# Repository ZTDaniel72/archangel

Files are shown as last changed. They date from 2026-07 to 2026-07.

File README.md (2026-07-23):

# Archangel

Archangel is an RC aircraft, that is designed to be efficient, and innovative.
It includes a 3D-printed airframe, a CUSTOM MADE ESP32 flight controller, and many more electric parts, discussed below.
The roadmap includes an FPV camera and more sensors with larger range, so that one day, this could stay in the air for 24 hours. But we are quite far from that right now lol.
I am building this because I love aviation and aeronautical engineering and I aspire to be one someday.
My goal is to get into TU Delft, in the Netherlands.

## Features

My current plan is:
Milestone 1: manual RC flight, custom firmware pass-through, failsafe, dual rates
Milestone 2: auto-level stabilization (MPU6500 + PID), SD flight logging
Milestone 3: altitude hold (BMP280), FPV camera
Wel shall see how far in we get, I think we can achieve all, but if not, milestone 2 will for sure be completed.

## Design

- Wingspan: ~110 cm, chord 17 cm (airfoil is a variation of this: http://airfoiltools.com/airfoil/details?airfoil=naca2412-il)
- Wing printed in 5 modules on a Bambu Lab P1S (25.6 cm bed), joined on a 10 mm carbon spar
- Ailerons: Incorporated into the wing structure
- Motor: Surpass Hobby C2836 1120KV, 3S, 9x6 prop
- CAD source: `cad/` (committed work-in-progress each session)

## Pictures
Current state as of 07.24:

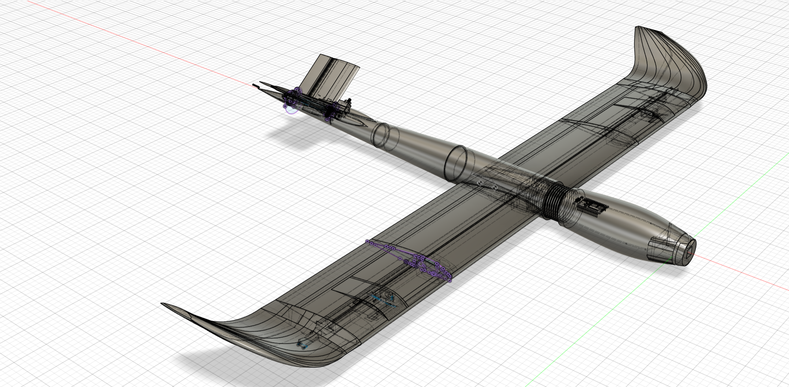
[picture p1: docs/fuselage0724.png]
Fuselage


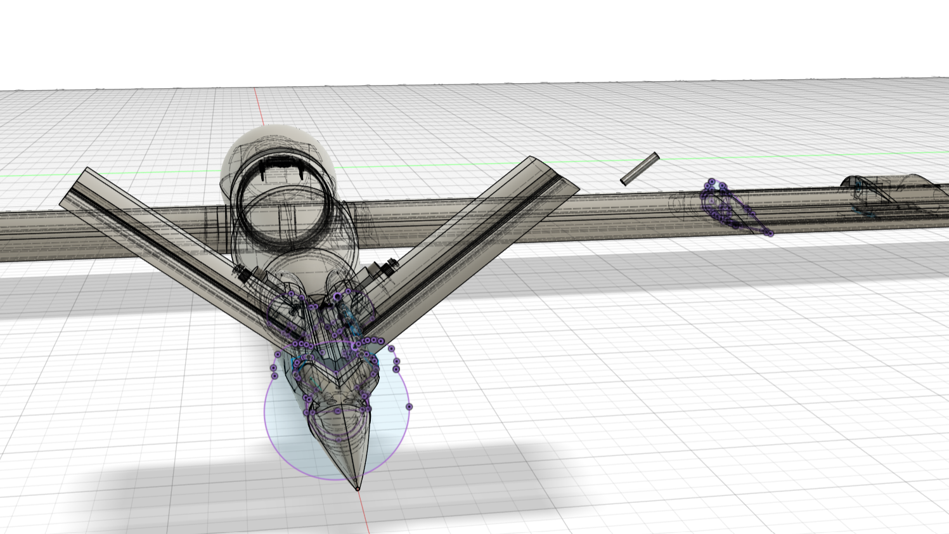
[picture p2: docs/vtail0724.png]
V-tail mount


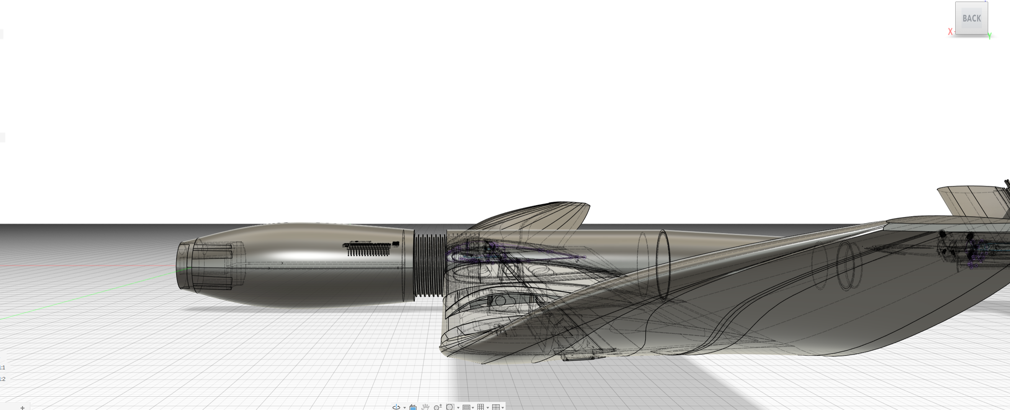
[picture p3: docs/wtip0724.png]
Wing preview


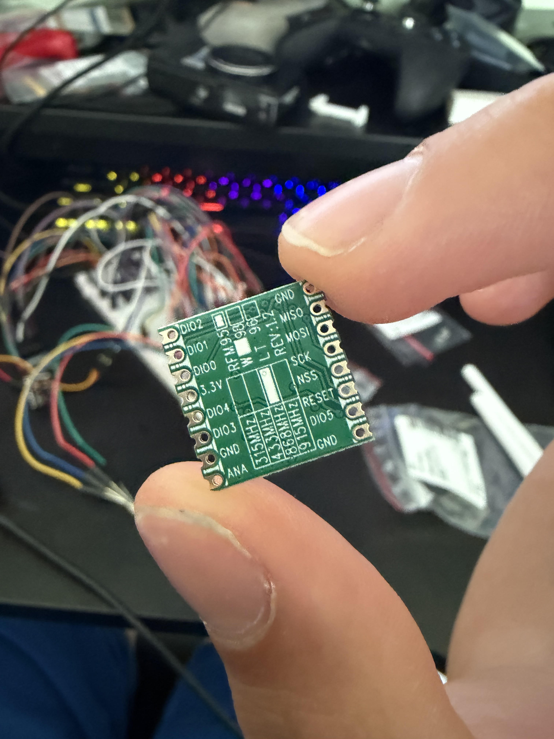
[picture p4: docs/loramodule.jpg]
LoRa


## Firmware

Custom flight controller on ESP32 (Arduino framework). Source in repo root.
Requires the ESP32Servo library.

## Steps to Reproduce

Start with printing the airframe. It it important that you use a LW material, like LW-ASA, which I am using for most of this print. The parts that arent LW-ASA are because that it simply doesnt have the precise properties
as other materials, such as PETG. i am printing the aileron wing structure in PETG for example. The entire wing consists of 11 pieces total. This is all for structural integrity.
The fuselage prints as circular segments split to fit the bed, each ending in a sleeve that slides into the next; walls run 1–1.2mm through the skin and thicken to 3mm at the joints,
the nose ring, and the wing saddle, which print in other materials for stiffness.
The two V-tail panels are NACA 0009, single-wall, solid only at the root tongue, and the motor firewall prints in ASA or PA6-CF at high density with the C2836 bolt circle and a built-in 2° down / 2° right thrust offset.
For early flights, treat the winglets as optional swap-ons.

Assemble from the spar outward. Thread the carbon spar setup through all wing modules, epoxy them to each other and to the spar.
Glue the fuselage segments at their sleeves and use acetone to bond them together chemically
Print the firewall with the nose, but with two separate materials, and bolt the motor down over washers.
Plug each V-tail panel into its angled root slot at a 105–110° included angle, epoxy them, and check by eye that both sit at identical incidence and dead parallel to the fuselage centreline.

Build the electronics as one stack. On perfboard, solder the ESP32 together with the MPU6500+BMP280 on I2C, the microSD module, a 10k/2.2k divider off the battery for voltage sensing, and the RGB status LED behind 220Ω resistors.
Fit four servos: two ailerons in the outer wing segments, two ruddervators at the tail,each driving its surface through an arm, short pushrod and control horn, hinged with a little hole in the part that the horn pushes and then put a little rod of metal in the hole and tie it to the servo horn; no printed gears anywhere.
Run the receiver into the ESP32's input pins, the output pins out to the four servos and the ESC, and the ESC to the motor and battery through an XT60. Mount the battery on a tray that slides fore and aft, since that slide is how you'll trim the balance.

Flash the firmware last. Open the sketch in the Arduino IDE, install ESP32Servo, pick your board, and set every pin in config.h to match how you actually wired it.
Fill in the V-tail mixer where the loop leaves a TODO: each ruddervator is elevator plus-or-minus rudder, and you verify the signs on the bench both surfaces up should mean nose-up, a rudder input should send them opposite ways.
Then bench-test with the propeller removed, always: confirm the sticks move the right surfaces the right way, kill the transmitter to proe the failsafe cuts throttle and centres everything, check dual rates on the AUX switch, and confirm the motor spins the correct direction, swapping any two motor wires if it doesn't.
Finish with balance and the maiden flight. Slide the battery until the CG sits about 30% of the chord back from the leading edge, erring nose-heavy.
set aileron and ruddervator throws to ±15–20°, weigh the aircraft aiming under about 900g, then hand-launch it level and firm at roughly two-thirds throttle in calm air over an open field, well 
clear of people and within local rules. Trim for hands-off level flight on the gentle rate before you go exploring the sport rate.

## Safety notes

<!-- Required by shipping guide. Keep and expand these: -->
- LiPo batteries: charge only on a balance charger, never unattended, store at storage voltage
- Printing: LW-PLA and PLA soften around 55–60°C, so never leave the airframe in a hot car; structural parts near the motor are printed in ASA or PA6-CF for exactly this reason.
- Arming: always connect the flight battery last, with the throttle already at zero and the transmitter on first; disconnect the battery before doing anything near the prop.
- ALL bench tests are done with the propeller removed
- Electrical: the ESC's BEC powers the electronics, so don't back-feed a second power source; insulate solder joints with heat-shrink, and check for shorts before the first power-up.
- Failsafe check: Do a test to see if the failsafe actually triggers when going out of range
- Failsafe: on signal loss the firmware cuts throttle and centers surfaces
- Fly only in open areas away from people, per local (Hungarian/EU) drone regulations

## Credits

- Airfoil profile imported from airfoiltools.com (http://airfoiltools.com/airfoil/details?airfoil=naca2412-il)
- Everything else (airframe CAD, firmware, electronics integration): me

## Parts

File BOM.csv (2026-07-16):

Category | Part | Qty | Part number / type | Source | Unit price (HUF) | Line total (HUF) | Price basis | Status
Electronics | ESP32 dev board | 1 | NodeMCU-ESP-32S (100.379.61) | hestore.hu | 2913 | 2913 | net actual | ordered
Electronics | IMU + barometer module | 1 | MPU6500-BMP280-M (100.440.23) | hestore.hu | 5037 | 5037 | net actual | ordered
Electronics | MicroSD card module | 1 | MICROSD-MODULE (100.420.87) | hestore.hu | 274 | 274 | net actual | ordered
Electronics | Perfboard 83x54mm | 2 | HS-005 (100.430.91) | hestore.hu | 516 | 1032 | net actual | ordered
Electronics | Breadboard 830pt | 1 | BB-102 630/200 (100.285.27) | hestore.hu | 1449 | 1449 | net actual | ordered
Electronics | Jumper wires M-M 40p | 1 | RC-40-10/MM (100.366.29) | hestore.hu | 657 | 657 | net actual | ordered
Electronics | Resistor 10k | 10 | metal film THT (100.204.46) | hestore.hu | 57 | 570 | net actual | ordered
Electronics | Resistor 2.2k | 10 | metal film THT (100.205.25) | hestore.hu | 7 | 70 | net actual | ordered
Electronics | Resistor 220R | 10 | metal film THT (100.204.34) | hestore.hu | 13 | 130 | net actual | ordered
Electronics | RGB LED 5mm common cathode | 5 | EVL-504-90-CC (100.375.96) | hestore.hu | 80 | 400 | net actual | ordered
Tools | Soldering station 60W | 1 | Fahrenheit 28005 (100.409.96) | hestore.hu | 5423 | 5423 | net actual | ordered
Tools | Soldering tips (spare) | 1 | 28005A 2-pack (100.410.34) | hestore.hu | 927 | 927 | net actual | ordered
Tools | Flux 40g | 1 | FP1035 (100.311.35) | hestore.hu | 780 | 780 | net actual | ordered
Powertrain | Brushless motor | 1 | Surpass Hobby C2836 1120KV | owned | 0 | 0 | owned | owned
Powertrain | ESC 40A with BEC | 1 | TBD | RC shop | 6000 | 6000 | estimate | to buy
Powertrain | Propeller 9x6 | 2 | TBD | RC shop | 800 | 1600 | estimate | to buy
Powertrain | Propeller 10x5 | 2 | TBD | RC shop | 800 | 1600 | estimate | to buy
Power | LiPo battery 3S 2200mAh | 2 | TBD | RC shop | 7000 | 14000 | estimate | to buy
Power | LiPo balance charger | 1 | TBD | RC shop | 8000 | 8000 | estimate | to buy
Power | XT60 connector pairs | 3 | TBD | RC shop | 500 | 1500 | estimate | to buy
Radio | Transmitter + receiver | 1 | existing set | owned | 0 | 0 | owned | owned
Servos | Servo 9g (4 needed + 2 spare) | 6 | SG90 / MG90S | RC shop or hestore.hu | 1000 | 6000 | estimate | to buy
Structure | Carbon spar tube 10mm x 1.3m | 1 | TBD | hobby/model shop | 5000 | 5000 | estimate | to buy
Structure | Carbon rod 3-4mm (longerons/anti-rotation) | 2 | TBD | hobby/model shop | 1500 | 3000 | estimate | to buy
Structure | CA glue + epoxy + hinge tape | 1 | TBD | hobby shop | 3000 | 3000 | estimate | to buy
Filament | LW-PLA (wing + tail skins) | 1 | any brand ~1kg | 3D shop | 9000 | 9000 | estimate | to buy
Filament | PLA (nose ring | wing saddle | structure) | 1 | any brand ~1kg | owned / 3D shop | 6000 | 6000 | estimate | to buy
Filament | ASA or PA6-CF (motor mount / firewall) | 1 | any brand ~0.5kg | 3D shop | 12000 | 12000 | estimate | to buy
Telemetry | LoRa module - plane (868MHz EU) | 1 | RFM95W / SX1276 868MHz | RC/electronics shop | 3200 | 3200 | estimate | to buy
Telemetry | LoRa module - ground (868MHz EU) | 1 | RFM95W / SX1276 868MHz | RC/electronics shop | 3200 | 3200 | estimate | to buy
Telemetry | 868MHz antenna | 2 | SMA/uFL whip | RC/electronics shop | 800 | 1600 | estimate | to buy
Telemetry | ESP32 - ground LoRa bridge | 1 | NodeMCU-ESP-32S | hestore.hu | 2913 | 2913 | estimate | to buy
TOTAL | Approx. total (net; estimates included) |  |  |  |  | ~112000 | mixed

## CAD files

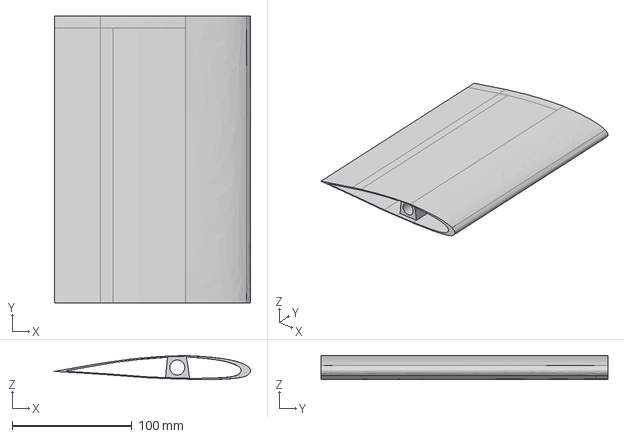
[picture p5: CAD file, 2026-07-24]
cad/mainwing.step
164.0 x 240.0 x 20.1 mm

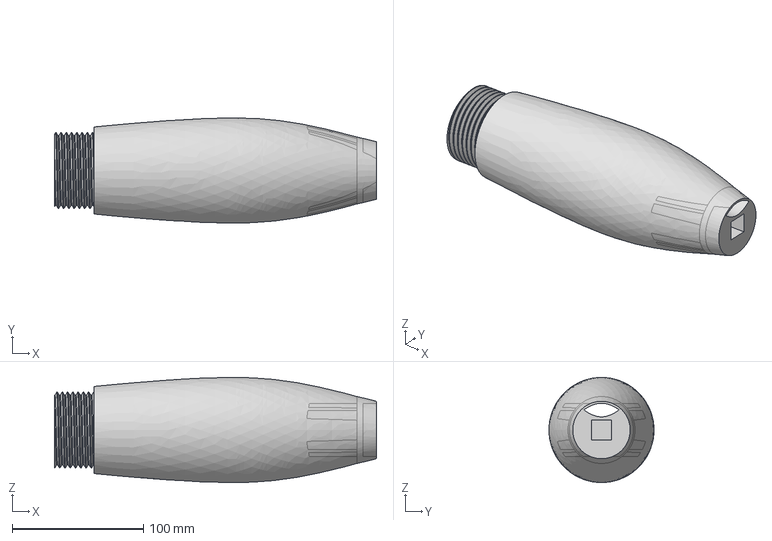
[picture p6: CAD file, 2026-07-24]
cad/nose.step
245.0 x 80.1 x 80.0 mm

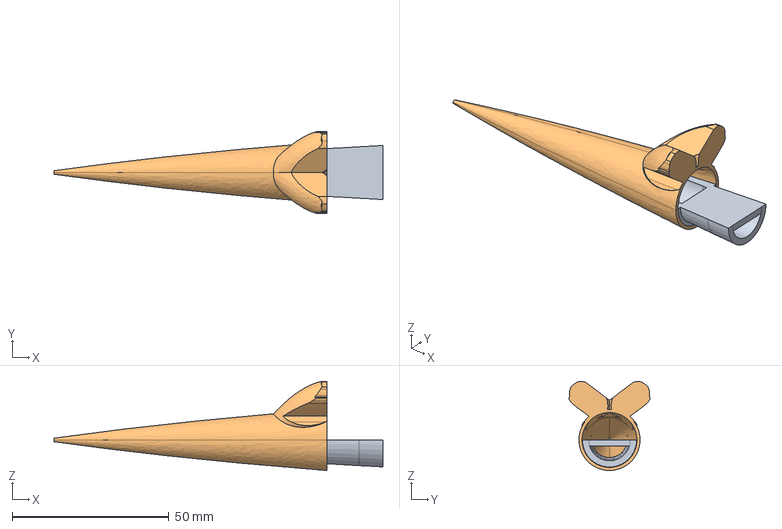
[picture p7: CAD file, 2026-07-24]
cad/tail5.step
105.0 x 26.1 x 28.4 mm

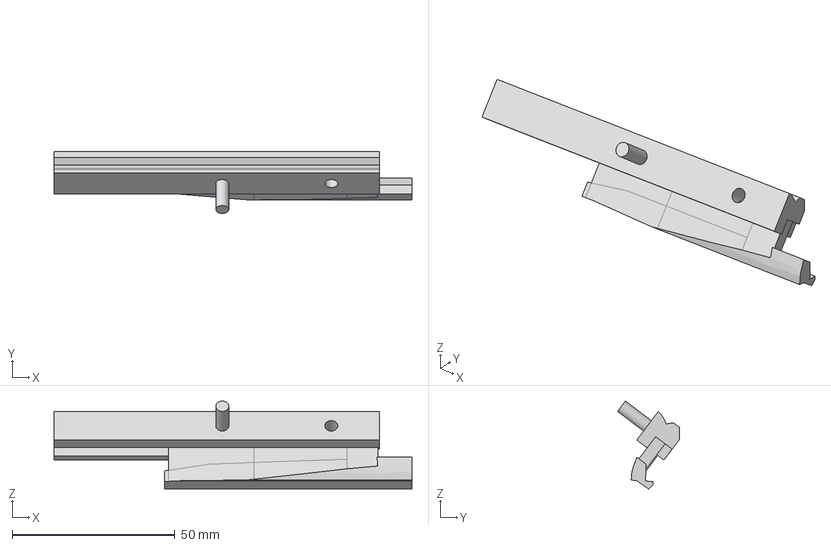
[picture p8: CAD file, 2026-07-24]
cad/ruddervator_connr.step
109.9 x 19.0 x 27.0 mm

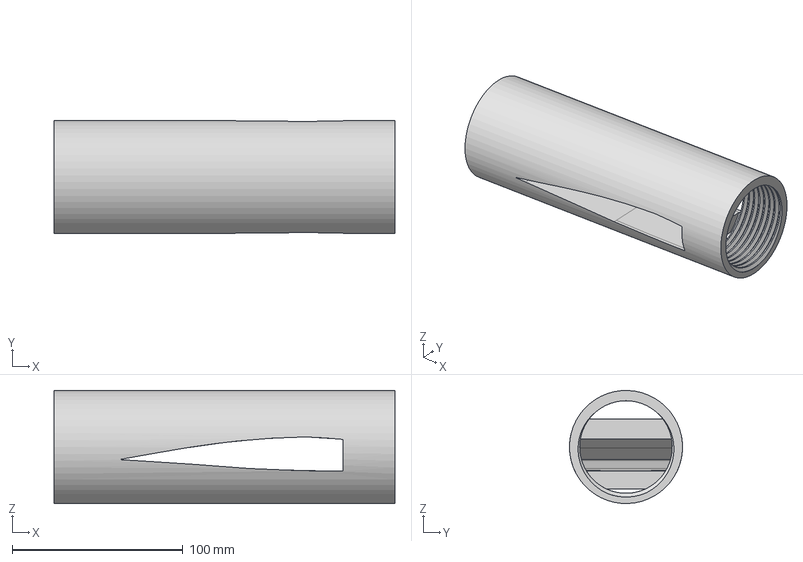
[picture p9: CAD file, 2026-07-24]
cad/fuselage2.step
200.0 x 66.3 x 66.3 mm

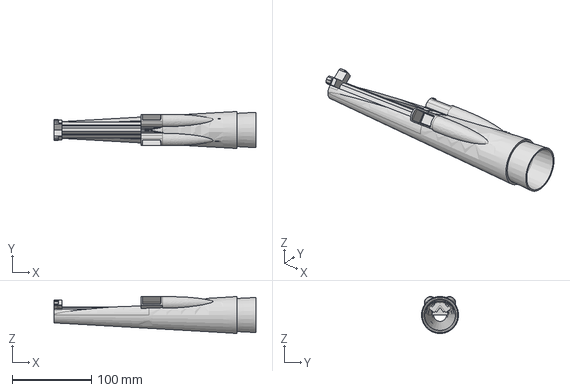
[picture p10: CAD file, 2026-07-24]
cad/fuselage4.step
255.0 x 46.7 x 46.7 mm

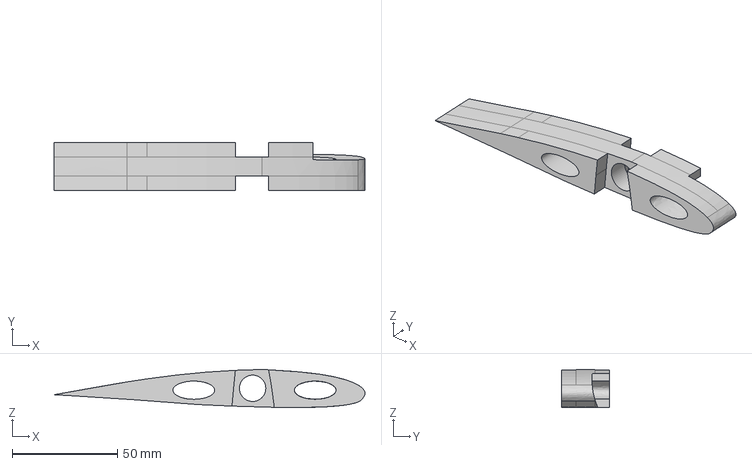
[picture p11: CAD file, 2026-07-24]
cad/fus_wing_innerR.step
147.6 x 23.0 x 18.1 mm

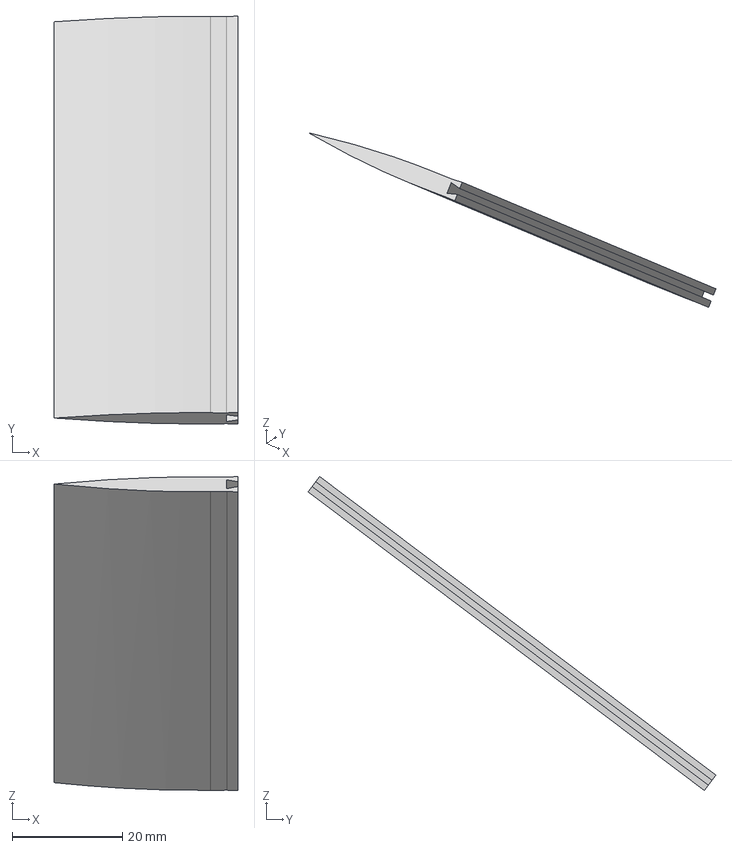
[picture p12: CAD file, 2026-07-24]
cad/ruddervatorflapR.step
33.3 x 74.0 x 57.0 mm

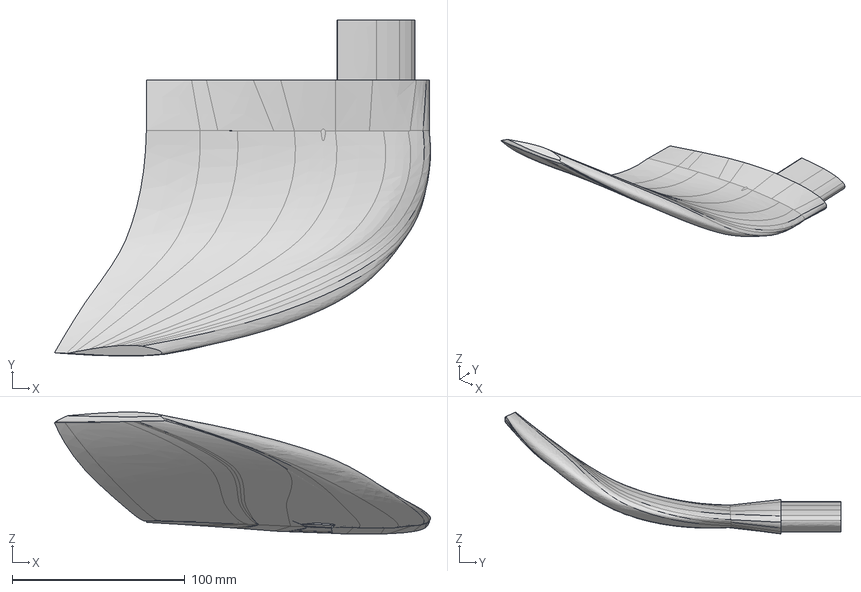
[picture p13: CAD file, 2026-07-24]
cad/wingtipR.step
217.9 x 194.9 x 70.6 mm

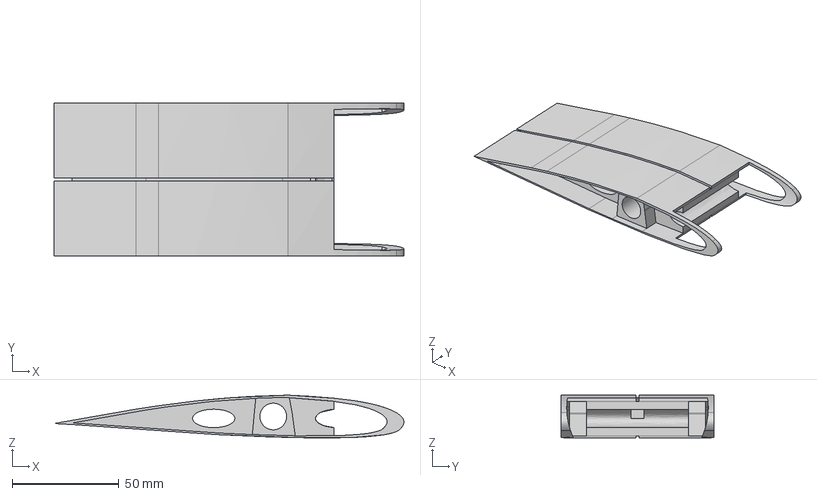
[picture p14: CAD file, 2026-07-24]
cad/inner_wingconn.step
164.0 x 71.5 x 20.1 mm

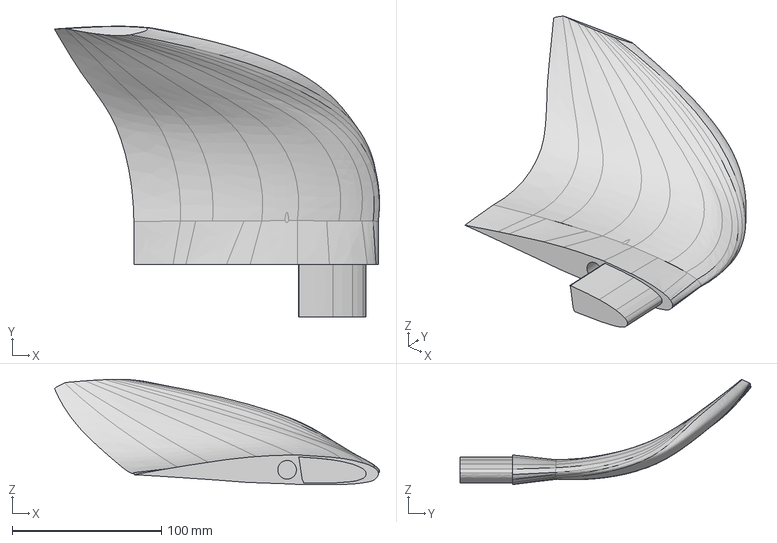
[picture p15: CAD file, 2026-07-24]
cad/wingtipL.step
217.9 x 194.9 x 70.6 mm

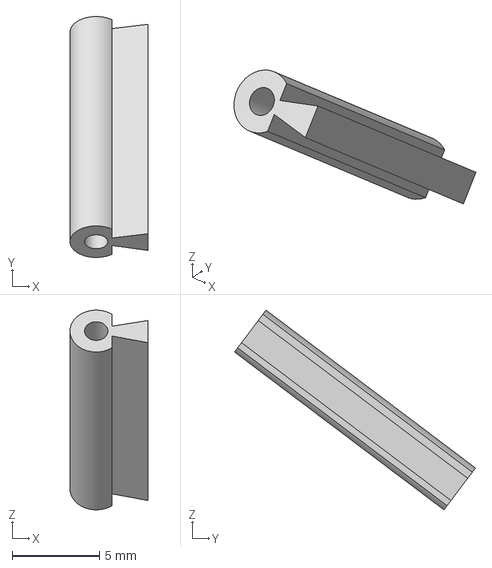
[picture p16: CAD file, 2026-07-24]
cad/flap_vator_connector.step
4.46 x 13.8 x 11.4 mm

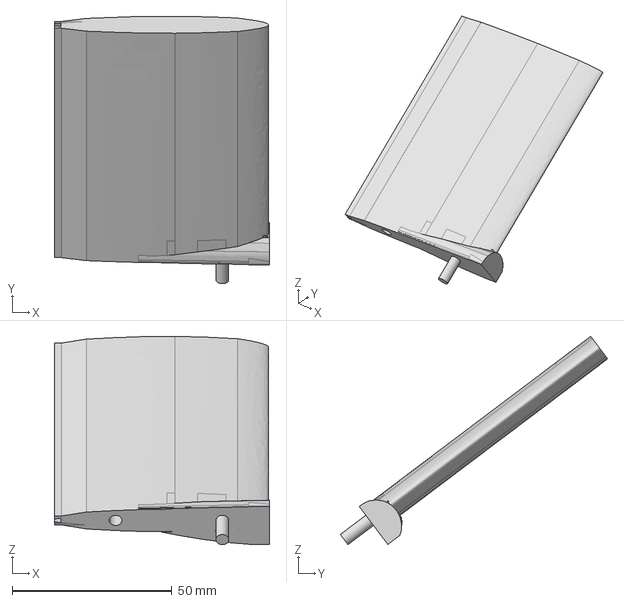
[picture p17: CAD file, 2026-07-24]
cad/ruddervatorL.step
67.3 x 83.8 x 65.3 mm

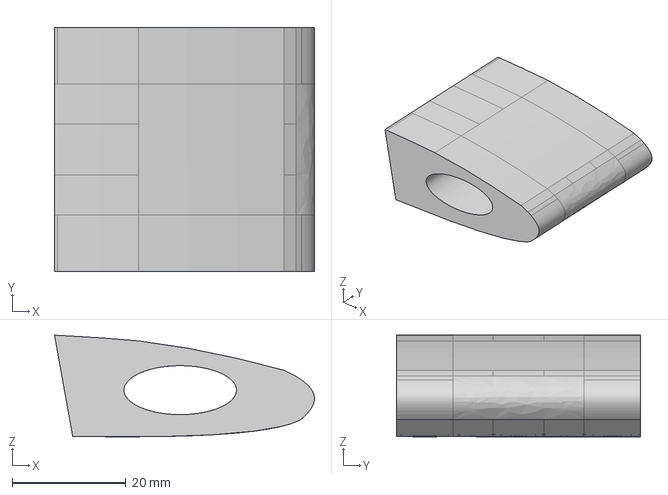
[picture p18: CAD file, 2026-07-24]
cad/aileroninncerconn.step
45.8 x 43.0 x 17.9 mm

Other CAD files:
cad/ruddervatorflapL.step
cad/fus_wing_innerL.step
cad/ruddervatorR.step
cad/fuselage3.step
cad/ruddervator_connl.step
cad/servowingL.step
cad/servowingR.step

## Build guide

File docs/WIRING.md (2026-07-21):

# Archangel bench wiring guide (Milestone 1)

Total beginner friendly. Follow top to bottom. Do NOT connect the flight
battery until the step that says so. NO PROPELLER ON THE MOTOR. EVER, on
the bench.

## The parts in front of you

- ESP32 board (NodeMCU-ESP-32S). Pins are labeled on the board itself in
  tiny white text. The labels we use: `P34 P35 P32 P33 P18 P19 P21 P23`,
  `VIN` (this is 5V from USB), and `GND` (there are several GND pins,
  they are all the same).
- Receiver (the small box that came with your transmitter). It has rows
  of 3-pin channels labeled CH1..CH6. On each row:
  the pin CLOSEST to the channel label / inner side = SIGNAL,
  middle = + (power), outer = - (ground). If your receiver is different,
  look up its pinout, but FlySky iA6B style is: signal on top row,
  + in middle row, - on bottom row.
- Servo plug (3 wires): ORANGE (or yellow/white) = signal,
  RED = + power, BROWN (or black) = ground.
- Breadboard: the two long rows along each edge are "rails". All holes
  in one rail row are connected together. We use one rail row as the
  GROUND BUS (everything's ground meets here) and another as the 5V BUS.
- Jumper wires: M-M = pin on both ends, M-F = pin on one end, socket on
  the other. Receiver and servo plugs need the PIN end pushed into them,
  so receiver->breadboard connections use M-M or M-F depending on side.

## Phase 1: receiver only (power comes from USB)

Goal: the ESP32 reads your transmitter sticks. Nothing moves yet.

1. Unplug everything. ESP32 NOT connected to USB yet.
2. Put the ESP32 across the middle groove of the breadboard if it fits,
   or leave it beside the breadboard and use M-F jumpers to its pins.
3. Build the ground bus: jumper from any ESP32 `GND` pin to the blue (-)
   rail of the breadboard.
4. Build the 5V bus: jumper from ESP32 `VIN` to the red (+) rail.
   (With USB plugged in, VIN carries about 5V. That is enough to power
   the receiver.)
5. Receiver power: M-F jumper from the red (+) rail to the MIDDLE pin of
   receiver CH1 row. Another from the blue (-) rail to the OUTER pin of
   the CH1 row. (Power on any one channel row powers the whole receiver.)
6. Receiver signals to ESP32 (SIGNAL pin of each channel row):
   - CH1 signal -> ESP32 `P34`   (aileron / right stick left-right)
   - CH2 signal -> ESP32 `P35`   (elevator / right stick up-down)
   - CH3 signal -> ESP32 `P32`   (throttle / left stick up-down)
   - CH5 signal -> ESP32 `P33`   (the switch you assigned / AUX)
   If CH5 does nothing later, your transmitter may need the switch
   assigned to channel 5 in its own menu (AUX setup).
7. Now plug the ESP32 into the laptop by USB. Receiver LED should light
   (solid if bound to the transmitter).
8. Transmitter ON. Open Serial Monitor (115200). With the debug print in
   loop(), you should see four numbers around 1000-2000 that follow the
   sticks. Write down which stick moves which number.

Phase 1 is DONE when all four values track their sticks.

## Phase 2: one servo (still USB power)

Goal: stick moves servo, through your firmware.

9. Take ONE servo. Push three M-M jumpers into its plug:
   - BROWN  -> blue (-) rail
   - RED    -> red (+) rail
   - ORANGE -> ESP32 `P18`
10. Move the right stick left-right. The servo should follow.
11. Flip the AUX switch: the throw should get bigger/smaller
    (dual rates). One servo on USB power is fine, do not add more yet.

Phase 2 is DONE when the servo mirrors the stick.

## Phase 3: full rig with ESC power (NO PROP!)

Goal: everything powered properly, all 4 servos + ESC.

12. UNPLUG USB and the battery (nothing powered while wiring).
13. Solder an XT60 onto the ESC battery wires if not done
    (red = +, black = -, heat-shrink both).
14. The ESC's thin 3-wire lead (its BEC) plugs like a servo:
    - its BROWN/BLACK -> blue (-) rail
    - its RED         -> red (+) rail   <- the BEC now FEEDS the rail
    - its ORANGE/WHITE (throttle signal) -> ESP32 `P23`
    IMPORTANT: from now on the red rail is powered by the BEC, NOT by
    VIN. REMOVE the jumper between VIN and the red rail from step 4.
    Ground stays shared: ESP32 GND remains connected to the blue rail.
    (Common ground = mandatory. Never remove that one.)
15. All four servos now connect like step 9:
    brown -> blue rail, red -> red rail, signals:
    - Left aileron  -> `P18`
    - Right aileron -> `P19`
    - Ruddervator L -> `P21`  (elevator output in current firmware)
    - Ruddervator R -> (added when the V-tail mixer is written)
16. Receiver stays as wired (its power now also comes from the BEC rail).
17. Motor: secured/clamped down, NO propeller, wires clear.
18. Power-up ORDER, every single time:
    a) Transmitter ON, throttle stick fully DOWN.
    b) ESP32 USB in (for serial monitor + its own power).
    c) Flight battery -> ESC XT60. ESC beeps its startup melody.
19. All four servos should follow sticks. Wiggle everything. If the
    ESP32 randomly reboots while servos move: the BEC is too weak,
    note it, order a separate 5V UBEC.

## Phase 4: throttle + failsafe test

20. Fingers, hair, wires AWAY from the motor. Gentle throttle: motor
    spins. Note direction (counterclockwise seen from the front is
    correct for a standard prop; to reverse, swap any two of the three
    thick motor wires).
21. FAILSAFE TEST: gentle throttle, then switch the TRANSMITTER OFF.
    Motor must stop and servos must center within ~half a second.
    TX back on: control returns. Repeat 3x.
22. Disconnect battery FIRST when done, then USB.

Film step 21. That video is the Milestone 1 demo.

## If something doesn't work

- Channel reads 0 in serial: wrong pin, or signal/ground swapped, or
  receiver not bound (LED blinking).
- Servo doesn't move but values track: servo power (red/brown) not on
  the rails, or signal on wrong pin.
- Everything dead in Phase 3: check the BEC red is on the red rail and
  the VIN jumper was removed; check common ground.
- ESC beeps endlessly, motor won't arm: throttle not at minimum, or
  throttle channel not reaching the ESC pin (`P23` in config.h).

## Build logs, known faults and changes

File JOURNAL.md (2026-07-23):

# Archangel Development Journal

-Started the project and ruminated on the exact idea of the UAV and all characteristics

## 2026-07-14: Aileron CAD

Recording: https://lapse.hackclub.com/timelapse/XpcbddsRDkn5
The aileron includes a very unique design that minimalizes drag, thanks to hidden servos inside the wing structure.
The servos capitalize on the flexibility of LW-PLA, therefore instead of needing aileron flaps, the whole wing flexes.

## 2026-07-14: Firmware skeleton

The firmware coding also started today, and I made some major improvements.
I havent coded in any type of C-based language in a long while so it took a bit to figure everything out.
In the end, I think that it went really well, and I am excited to test all of my code out for-real when my arduino and million other electrical components arrive.
I implemented a failsafe, dual rates and also coded the receiver pass-through

## 2026-07-15: Fuselage, Tail mount and more wing improvements + wingtip

Recording: https://lapse.hackclub.com/timelapse/FDi42ch49GMw
Another recording: https://lapse.hackclub.com/timelapse/CiaGbsH7okC-

This day was one of my largest so far, I sat down for a good while, just contemplating the best design choices.
I started off with some minor improvements to yesterday's wing shape and design, which also led me down a rabbit hole of efficient airfoils.
The wingtip was also designed this day, with a lot of hard streches, but I managed to figure out the design.
Some of the challenges included: the size and weight design of the tip, whilst also minimizing drag, but also making it look cool.
Then came the "final boss" of this CAD session: the fuselage.
I used a clever, tube-like design for the fuselage, so that it looks realistic.
I also made a rough design of the V-tail mount for the combined elevator and rudder design, which is also common in UAV-s today.

## 2026-07-16: Telemetry, ground station and battery

Today I quickly put together a simulated version of a ground station and what that would look.
I also decided on the LoRa, for long rage telemetry, which helps extend my range up kilometers even.
I thought through battery options and ended up on a Li-ion battery. The exact model is yet to be chosen.
Got LW-ASA instead of LW-PLA (they delivered the wrong one) but eventually I figured that this is in my favor, since ASA is more resistant to the sun and UV compared to PLA.
Today, i will start on the tail mixer, which is a complex code, especially because i would have to balance the operation on two wings instead of three.

## 2026-07-17 -> 2026-07-20: CAD design finishes

During this timeline, I improved and finished the whole entire CAD design of the UAV.
It "should" now work and fly. I gave it a sleek, modern look, with plenty space in the nose cone for future upgrades.
I was also in doubt in this period, since a couple of my account info got tangled up, but luckily everything was fixed and now we're back better than ever.

## 2026-07-21: Coding, soldering, and more coding

Today I set up the ESP32. I wired the receiver to the ESP32 and got it reading all of the RC channels, after a long hassle. It took ages, since there was an apparent driver problem.
I rewrote the receiver code to use pulseIn.
I also wrote the V-tail mixer, which will be used on the aircraft in the near future. It consists of two ruddervators sharing pitch and rudder. I tested it on real servos.
I built a python bench dashboard that shows the live channels, mixer outputs, and a V-tail animation, plus a pitch/roll screen, just like on real aircraft!
This was my first time ever soldering as well. I put together the MPU/GY-91 headers in a great battle.
I got the sensor talking over 12C, I read raw accelerometer data, and converted it into roll/pitch angles via mathematical formulas.
I wrote a complementary filter as well, so the gyro and accelerometer blend nicely. Then, I added gyro-bias calibration, so there is zero drifting while standing still.
I somehow managed to package it all as an IMU module in the main firmware.
Lastly, I got the BMP280 barometer talking finally. It reads altitude, and then I smoothed it out with a low-pass filter.
There were a lot of struggles with this session, but I am glad that I managed to hold on and keep calm. It lead me down a path that I will remember for a while.
In the next following days, I will be printing the airframe, and ordering the electronical parts necessary for the rest of this build.

All of the videos recorded during this session will be as an unlisted youtube link
You can find it here: https://youtube.com/shorts/0uXKaofNkJc?feature=share

## 2026-07-22: Major improvements

Today brought major improvements to both software, electronics, airframe and logistics.
In the software department, I:
1. folded the bmp 280 barometer into the firmware, so now we can track altitude. also added it to the desktop dashboard and it looks cleaner than ever.
2. i built gyro rate damping, which evolved into a !!FULL-SELF-LEVELLING PID CONTROLLER!! (it basically returns to level flight with a couple complicated calculations)
3. Reworked mode logic, after discovering that the FS-T4B is only 4 channel.
4. added an RGB status LED (blue calibrating, red failsafe, green armed/ok)
5. Hardened the failsafe with pull.down resistors on the input pins, therefore getting rid of phantom signals.
6. Added WiFi Phone Telemetry: The ESP32 now hosts its own wifi, and anyone can join it from their phone, then visit a live dashboard from their browser. This will work great for showing it to larger audiences, etc.
Whilst on the electronics:
1. Wired and bench-tested the motor+esc config, worked really well even though i didnt have a clamp so i had to hold the motor in my hands lol (dont try at home), it also showed on the ground station
2. Learned power architecture
3. charged the LiPo, so it can be used for flight.
Airframe: Fought (and hopefully) solved LW-ASA bed warping and major stringing. the filament seems to be damp, so I'll look into drying options. I also made the airframe more "3d printer friendly"
Logistics: Confirmed that I dont need a visa for Singapore, since I have a Hungarian passport. I also sorted out the spar plan(12mm tube, 1000mm long)

I am excited for the following days, cant wait to make a new demo video and re-ship once I have the 35 hours. I am getting really close!!

## 2026-07-23: The big day

I finally hit 35 hours, even surpassing that!
Today I did a lot of hardware stuff, mainly:
Solving SD card logging: It now logs flight telemetry data onto the SD card, and records every moment on the aircraft. Basically its "Black box".
The big one: LoRa long range telemetry links:
1. I soldered the RFM95W radio onto the flight controller, which was a well-fought battle-
2. Got SD and LoRa sharing one SPI Bus, which solved the chip-select conflict that came up during testing.
3. Wrote the plane side transmitter, now hooked up to LoRa.
4. Built the ground bridge, on my SECOND esp32. Soldered a whooooole new LoRa module all over again, which was once again a big pain, but in the end I figured it out.

Materials, design:
I decided that LW-ASA was not a good option for the integrated aileron wing design, since its foaming all over the place. Therefore, I went with PETG.
Redesigned the spar as a two-piece joined spar, since it has to fit into my carry on loll

AND finally, I BOUGHT THE TICKETS TO ARCANA!!
Singapore, IM ON MY WAY

Cant wait for what tomorrow holds.

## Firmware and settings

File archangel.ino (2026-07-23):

#include "config.h"
#include "receiver.h"
#include "outputs.h"
#include "imu.h"
#include "led.h"
#include "webui.h"
#include "sdlog.h"
#include "loralink.h"

void setup() {
    Serial.begin(115200);
    pinMode(2, OUTPUT);  digitalWrite(2, HIGH);  
    pinMode(26, OUTPUT); digitalWrite(26, HIGH);   
    rxInit();
    outputsInit();
    ledInit();
    ledSet(0,0,1);
    Serial.println("stay still, calibrating IMU...");
    imuInit();
    webuiInit();
    Serial.println("wifi up: connect to ARCHANGEL, open 192.168.4.1");
    Serial.println(sdInit() ? "Sd logging" : "sd fail");
    Serial.println(loraInit() ? "LoRa TX ready" : "LoRa FAIL - check wiring");
    Serial.println("online, ready for start");
}

static uint16_t applyRate(uint16_t pulse, float rate) {
    int centered = (int)pulse - PULSE_MID;
    return (uint16_t)(PULSE_MID + centered * rate);
}

static float pidStep(float target, float measured, float rate, float &integ) {
  float err = target - measured;
  integ += err * (1.0f / LOOP_HZ);
  integ = constrain(integ, -PID_ILIMIT, PID_ILIMIT);
  return PID_KP * err + PID_KI * integ - PID_KD * rate;
}

void loop() {
  webuiUpdate();
  static uint32_t lastRun = 0;
  if (millis() - lastRun < (1000 / LOOP_HZ)) return;
  lastRun = millis();
  imuUpdate();

  uint16_t roll  = rxGet(RX_ROLL);
  uint16_t pitch = rxGet(RX_PITCH);
  uint16_t thr   = rxGet(RX_THROTTLE);
  uint16_t aux   = rxGet(RX_AUX);
  uint16_t rudd  = rxGet(RX_RUDD);

  uint16_t ailL, ailR, ruddL, ruddR;

  static float rollInteg = 0, pitchInteg = 0;

  if (rxHealthy()) {
    
    rudd = applyRate(rudd, RATE_GENTLE);
    float rollTarget = ((int)roll - PULSE_MID) / 500.0f * PID_MAXANGLE;
    float pitchTarget = ((int)pitch - PULSE_MID) / 500.0f * PID_MAXANGLE;
    int rollOut = (int)pidStep(rollTarget, imuRoll(), imuRollRate(), rollInteg);
    int pitchOut = (int)pidStep(pitchTarget, imuPitch(), imuPitchRate(), pitchInteg);
    roll = (uint16_t)constrain(PULSE_MID + rollOut, PULSE_MIN, PULSE_MAX);
    pitch = (uint16_t)constrain(PULSE_MID + pitchOut, PULSE_MIN, PULSE_MAX);
    

    int ruddDefl = (int)rudd - PULSE_MID;
    ruddL = (uint16_t)((int)pitch + ruddDefl);
    ruddR = (uint16_t)((int)pitch - ruddDefl);
    ailL = roll;
    ailR = (uint16_t)(2 * PULSE_MID - roll);
    outputsWrite(ailL, ailR, ruddL, ruddR, thr);
  } else {
    ailL = ailR = ruddL = ruddR = FAILSAFE_SURFACE;
    thr = FAILSAFE_THROTTLE;
    outputsFailsafe();
  }
  static uint32_t lastSd = 0;
  if (millis() - lastSd >= 100) {
    lastSd = millis();
    sdLog(imuRoll(), imuPitch(), imuAlt(), thr, rxHealthy());
  }
  static uint32_t lastLora = 0;
  if (millis() - lastLora >= 250) {
    lastLora = millis();
    loraSend(imuRoll(), imuPitch(), imuAlt(), thr, rxHealthy());
  }
  webuiSet(imuRoll(), imuPitch(), imuAlt(), thr, rxHealthy());
  if (!rxHealthy()) ledSet(0,1,0);
  else ledSet(1,0,0);

  static uint32_t lastPrint = 0;
  if (millis() - lastPrint > 100) {
    lastPrint = millis();
    Serial.printf("ABN,%u,%u,%u,%u,%u,%u,%u,%u,%u,%d,%.1f,%.1f, %.1f\n",
            roll, pitch, thr, rudd, aux,
            ailL, ailR, ruddL, ruddR, (int)rxHealthy(), imuRoll(), imuPitch(), imuAlt());
  }
}

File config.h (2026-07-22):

#pragma once

#define PIN_RX_ROLL 34
#define PIN_RX_PITCH 35
#define PIN_RX_THROTTLE 32
#define PIN_RX_AUX 33
#define PIN_RX_RUDD 25

#define PIN_SERVO_AIL_L 18
#define PIN_SERVO_AIL_R 19
#define PIN_SERVO_RUDD_L 21   
#define PIN_SERVO_RUDD_R 22   
#define PIN_ESC 23
#define PIN_LED_R 13
#define PIN_LED_G 14
#define PIN_LED_B 27

#define PULSE_MIN 1000
#define PULSE_MID 1500
#define PULSE_MAX 2000

#define FAILSAFE_TIMEOUT_MS 500
#define FAILSAFE_THROTTLE PULSE_MIN
#define FAILSAFE_SURFACE PULSE_MID

#define RATE_SPORT 1.0f
#define RATE_GENTLE 0.6f
#define STAB_GAIN 2.0f
#define PID_KP 4.0f
#define PID_KI 0.5f
#define PID_KD 2.0f
#define PID_ILIMIT 200.0f
#define PID_MAXANGLE 45.0f


#define LOOP_HZ 100

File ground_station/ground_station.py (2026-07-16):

#!/usr/bin/env python3
# Archangel ground station.
# Run with no arguments for SIMULATION MODE: it generates fake telemetry so
# the whole app is testable with no hardware. Use --serial PORT for the real
# LoRa bridge once it exists.

import argparse
import math
import random
import sys
import time

import protocol


class SimTransport:
    def __init__(self, rate_hz=4.0, loss=0.05):
        self.dt = 1.0 / rate_hz
        self.loss = loss
        self.seq = 0
        self.t0 = time.time()

    def lines(self):
        while True:
            time.sleep(self.dt)
            self.seq = (self.seq + 1) & 0xFFFF
            t = time.time() - self.t0
            tele = protocol.Telemetry(
                seq=self.seq,
                t_ms=int(t * 1000),
                roll=25 * math.sin(t * 0.5),
                pitch=8 * math.sin(t * 0.3),
                yaw=(t * 20) % 360,
                alt_m=30 + 15 * math.sin(t * 0.1),
                vbat=max(9.6, 12.6 - t * 0.01),
                mode=1 if (int(t) // 5) % 2 else 0,
            )
            if random.random() < self.loss:
                continue
            yield protocol.encode(tele)


class SerialTransport:
    def __init__(self, port, baud=115200):
        try:
            import serial
        except ImportError:
            sys.exit("pyserial not installed. Run: pip install pyserial")
        self.ser = serial.Serial(port, baud, timeout=1)

    def lines(self):
        while True:
            raw = self.ser.readline().decode("utf-8", "replace")
            if raw:
                yield raw


class LinkStats:
    def __init__(self):
        self.received = 0
        self.lost = 0
        self.last_seq = None

    def update(self, seq):
        self.received += 1
        if self.last_seq is not None:
            gap = (seq - self.last_seq - 1) & 0xFFFF
            if gap < 1000:
                self.lost += gap
        self.last_seq = seq

    @property
    def loss_pct(self):
        total = self.received + self.lost
        return 100.0 * self.lost / total if total else 0.0


def render(t: protocol.Telemetry, stats: LinkStats):
    print("\033[2J\033[H", end="")
    print("=== ARCHANGEL GROUND STATION ===\n")
    print(f"  mode      {t.mode_name}")
    print(f"  roll      {t.roll:+6.1f} deg")
    print(f"  pitch     {t.pitch:+6.1f} deg")
    print(f"  yaw       {t.yaw:6.1f} deg")
    print(f"  altitude  {t.alt_m:6.1f} m")
    print(f"  battery   {t.vbat:6.2f} V  {_batt_bar(t.vbat)}")
    print(f"  uptime    {t.t_ms/1000:6.1f} s")
    print()
    print(f"  packets   {stats.received}   loss {stats.loss_pct:4.1f}%")
    if t.vbat < 10.5:
        print("\n  ** LOW BATTERY, LAND NOW **")


def _batt_bar(v, vmin=9.6, vmax=12.6):
    frac = max(0.0, min(1.0, (v - vmin) / (vmax - vmin)))
    n = int(frac * 20)
    return "[" + "#" * n + "-" * (20 - n) + "]"


def main():
    ap = argparse.ArgumentParser(description="Archangel ground station")
    ap.add_argument("--serial", metavar="PORT")
    ap.add_argument("--baud", type=int, default=115200)
    ap.add_argument("--sim", action="store_true")
    args = ap.parse_args()

    if args.serial:
        transport = SerialTransport(args.serial, args.baud)
        print(f"Listening on {args.serial} @ {args.baud} ...")
    else:
        transport = SimTransport()
        print("SIMULATION MODE: generating fake telemetry. Ctrl+C to quit.")
        time.sleep(1.0)

    stats = LinkStats()
    try:
        for line in transport.lines():
            tele = protocol.parse(line)
            if tele is None:
                continue
            stats.update(tele.seq)
            render(tele, stats)
    except KeyboardInterrupt:
        print("\nGround station stopped.")


if __name__ == "__main__":
    main()

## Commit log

2026-07-14 feat: initial firmware skeleton (receiver passthrough + failsafe)
    [archangel.ino, config.h, outputs.cpp]
2026-07-16 Add CAD design files, BOM, README, journal, and firmware fixes
    [BOM.csv, Fuselage(unfinished).step, ailconnector.step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]
2026-07-16 Add ground station, LoRa telemetry, screenshots, updated BOM
    [BOM.csv]
2026-07-24 cad files
    [Fuselage(unfinished).step, ailconnector.step, aileroninncerconn.step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]
